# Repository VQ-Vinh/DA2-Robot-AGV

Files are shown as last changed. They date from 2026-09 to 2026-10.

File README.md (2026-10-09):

<div align="center">

# 🤖 DA2 · Robot AGV kho hàng kiểu Kiva

**Xe tự hành chui gầm, nâng kệ hàng, chở tới trạm lấy hàng rồi trả về ô và tự đi sạc.**

ROS 2 Jazzy · Nav2 · Gazebo Harmonic · Raspberry Pi 4 · STM32F4 · FreeRTOS

[Mô phỏng & ROS 2](RasPi/README.md) · [Nhật ký quá trình](REPORT.md) · [Firmware STM32](STM32/)

</div>

---

## ✨ Xe làm được gì

| 📦 Nhận đơn | 🛞 Chui gầm & nâng kệ | 🚚 Chở tới trạm | 🔋 Tự sạc | 🚨 Xử lý sự cố |
|:---:|:---:|:---:|:---:|:---:|
| Hàng đợi, ưu tiên, huỷ đơn trên web | Lidar tìm 4 chân kệ, căn giữa ≤ 1 cm | Nav2 + vùng cấm, footprint đổi theo tải | Pin thấp thì về trạm, sạc đủ mới nhận đơn | Dừng khẩn, đường bị chặn, rơi kệ |

---

## 🗺️ Kho hàng

```mermaid
flowchart LR
    subgraph W["Tây kho"]
        IN(["🔵 Khu nhập hàng"])
        CH(["🟢 Trạm sạc"])
        PK(["🟠 Trạm lấy hàng"])
    end
    subgraph N["Dãy bắc · xe vào hướng +y"]
        N1[N1] --- N2[N2] --- N3[N3] --- N4[N4] --- N5[N5]
    end
    AISLE{{"Lối giữa rộng 2.45 m"}}
    subgraph S["Dãy nam · xe vào hướng −y"]
        S1[S1] --- S2[S2] --- S3[S3] --- S4[S4] --- S5[S5]
    end
    W <--> AISLE
    AISLE <--> N
    AISLE <--> S
```

8 kệ 0.75 × 0.75 m nằm trong 10 ô, cách nhau 1.1 m. Bố trí lấy từ một file duy nhất, [`shelves.yaml`](RasPi/src/agv_mission/config/shelves.yaml), từ đó sinh ra world Gazebo, danh sách dock của Nav2 và mặt nạ vùng cấm.

---

## 🧩 Kiến trúc

```mermaid
flowchart TB
    subgraph USER["👤 Người vận hành"]
        WEB["🌐 Web dashboard<br/>điện thoại / laptop"]
    end

    subgraph PI["🍓 Raspberry Pi 4 · ROS 2 Jazzy"]
        DASH["web_dashboard<br/>REST + SSE"]
        OM["order_manager<br/>hàng đợi · SQLite · sự cố"]
        NAV["Nav2<br/>planner · RPP · docking · behaviors"]
        LOC["AMCL + EKF<br/>imu_bias"]
        PM["payload_manager<br/>lọc scan · footprint"]
        SD["shelf_detector<br/>tìm 4 chân kệ"]
    end

    subgraph MCU["⚙️ STM32F407 · FreeRTOS"]
        SPD["PID tốc độ + feedforward"]
        ENC["Encoder"]
        DRV["L298N × 2"]
    end

    LIDAR(["📡 YDLidar"])
    IMU(["🧭 BNO055"])
    BAT(["🔋 INA226"])
    MOT(["4 × GA25-370"])

    WEB <-->|HTTP| DASH
    DASH <--> OM
    OM -->|goal, dock| NAV
    NAV -->|cmd_vel| MCU
    LIDAR --> PM --> NAV
    LIDAR --> SD --> NAV
    LOC --> NAV
    MCU -->|odom, IMU, pin| LOC
    IMU --> MCU
    BAT --> MCU
    SPD --> DRV --> MOT
    MOT --> ENC --> SPD
```

---

## 🔁 Một đơn hàng

```mermaid
sequenceDiagram
    autonumber
    actor U as 👤 Người vận hành
    participant OM as order_manager
    participant N as Nav2 / docking
    participant L as Cơ cấu nâng

    U->>OM: add ke_03 tram_lay_hang
    OM->>N: tới staging trước ô (đoạn cuối thẳng)
    OM->>N: chui gầm theo chân kệ (lidar)
    OM->>OM: kiểm tra hướng ≤ 8°
    OM->>L: nâng
    OM->>N: lùi ra · chở tới trạm
    OM-->>U: đã tới, chờ lấy hàng
    U->>OM: confirm
    OM->>N: về ô · vào ô theo bản đồ
    OM->>OM: kiểm tra hướng ≤ 8°, vị trí ≤ 10 cm
    OM->>L: hạ
    OM->>N: lùi ra · về trạm sạc
```

---

## 🚨 Khi có sự cố

```mermaid
flowchart LR
    E{"Sự cố"} -->|Dừng khẩn<br/>Đường bị chặn > 60 s| R["⏸️ Xe dừng<br/>chờ người"]
    E -->|Rơi kệ<br/>Cơ cấu nâng lỗi| F["⛔ Đơn lỗi<br/>kệ chưa rõ vị trí"]
    E -->|Lỗi trước khi nâng kệ| Q["↩️ Trả đơn về hàng đợi"]
    R -->|"Đã xử lý"| C["▶️ Làm lại đúng bước đang dở"]
    F -->|"shelf ke_xx Ny"| C2["📍 Cập nhật vị trí kệ"]
```

```mermaid
flowchart LR
    B["🔋 Pin < 30 % + 10 % dự trữ cho đơn"] --> G["Về trạm sạc"] --> H["Sạc tới 80 %"] --> J["Nhận đơn tiếp"]
```

---

## 🧭 Định vị

```mermaid
flowchart LR
    ENC["Encoder bánh"] --> WO["/wheel/odom<br/>vx tin được · wz kém"]
    GYRO["Gyro"] --> RAW["/imu/raw"] --> IB["imu_bias<br/>học bias khi bánh đứng yên"] --> IMU["/imu"]
    WO --> EKF["EKF"]
    IMU --> EKF
    EKF --> ODOM["/odom"]
    ODOM --> AMCL["AMCL + bản đồ"]
    SCAN["Lidar"] --> AMCL
    AMCL --> MAP["vị trí trên bản đồ"]
```

---

## 📊 Kết quả trong mô phỏng

8 đơn liên tiếp, có mô phỏng vùng chết động cơ giống firmware (≥ 100 RPM):

| | Trước khi chỉnh | Sau khi chỉnh |
|---|:---:|:---:|
| Đơn xong | 8/8 | **8/8** |
| Thời gian TB / đơn | 105 s | **88 s** |
| Quay thừa khi trả kệ (lớn nhất) | 4198° | **75°** |
| Nav2 phải tự hồi phục | nhiều lần | **0** |
| Góc trôi khi đứng yên 5 phút | 2.4°–12° | **0.05°** |

| Bài thử | Kết quả |
|---|---|
| Chui gầm theo chân kệ (kệ đặt lệch) | 6/6, lệch ngang ≤ 0.9 cm · theo bản đồ chỉ 2/6 |
| Đơn hàng + ưu tiên + huỷ | 3/3 |
| Sạc giữa chừng | 3/3 đơn, tự về sạc rồi làm tiếp |
| Sự cố (dừng khẩn, rơi kệ, tường chắn) | dừng khẩn & rơi kệ: 4/4 lần · tường chắn: 2/4 lần |

Cách đo, các lần sai và cách sửa: [REPORT.md](REPORT.md).

---

## 🛣️ Tiến độ

```mermaid
timeline
    title Các mốc chính
    09/2026 : Firmware STM32 · PID tốc độ
            : Chọn ROS 2 Jazzy + Gazebo Harmonic
    10/2026 : Mô phỏng · EKF · SLAM · Nav2
            : Web dashboard
            : Kiva 1 · nâng kệ · Kiva 2 · tìm chân kệ
            : Kiva 3 · đơn hàng · Kiva 4 · pin & sạc · Kiva 5 · sự cố
    Tiếp theo : Cầu nối UART Pi ↔ STM32
              : PCB · khung xe · chốt định vị mặt nâng
              : Chạy trên xe thật
```

---

## 🚀 Chạy thử

```bash
# WSL Ubuntu 24.04 + ROS 2 Jazzy (xem RasPi/README.md để cài)
cd ~/agv_ws && colcon build --symlink-install && source install/setup.bash
ros2 launch agv_gazebo sim.launch.py nav:=true
```

Sau đó mở **http://localhost:8080**, chọn kệ và trạm rồi bấm **Tạo đơn**.

---

## 📁 Cấu trúc repo

```mermaid
flowchart LR
    R["📂 Src"] --> RP["📂 RasPi/src<br/>ROS 2"]
    R --> ST["📂 STM32<br/>firmware"]
    R --> RE["📄 REPORT.md<br/>nhật ký"]
    R --> CA["📂 CAD<br/>mô hình FreeCAD"]
    RP --> D["agv_description<br/>URDF"]
    RP --> G["agv_gazebo<br/>world · sim · bài thử"]
    RP --> L["agv_localization<br/>EKF · imu_bias"]
    RP --> NV["agv_navigation<br/>SLAM · Nav2 · docking"]
    RP --> M["agv_mission<br/>đơn hàng · dashboard"]
    ST --> APP["App<br/>logic"]
    ST --> MOD["Modules<br/>driver"]
    ST --> CORE["Core<br/>CubeMX sinh"]
```

<div align="center">

Đồ án 2 · HK261

</div>

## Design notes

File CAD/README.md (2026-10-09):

# CAD – mô hình cơ khí xe AGV

File: `agv.FCStd` (FreeCAD 1.1). Mở bằng **File → Open**.

## Quy ước

- Đơn vị mm. Gốc toạ độ = `base_footprint` của URDF (mặt đất, tâm xe); X tiến, Y trái, Z lên.
- Giá trị âm trong `Params` phải gõ dạng `=-82 mm` (có dấu `=`), nếu không FreeCAD lưu thành chữ.
- Mọi kích thước nằm trong bảng **`Params`** (đầu cây Model). Sửa giá trị ở cột B rồi nhấn `Ctrl+R`, mô hình tự cập nhật. Cột C ghi nguồn; dòng có chữ `UOC LUONG` là số chưa đo trên linh kiện thật.
- Hai tấm mica là PartDesign Body (sketch + pad + lỗ), dùng để xuất DXF cắt laser. Động cơ, lidar và Pi là model tải về; bánh và gá động cơ tự vẽ.

## Các cụm

| Cụm | Nội dung |
|---|---|
| `Chassis` | 2 tấm mica 300 × 300 × 5 mm, 4 trụ ốc 100 mm. Tầng 1 có 4 chỗ khoét cho bánh, 4 lỗ chữ nhật 16 × 8 mm luồn dây động cơ, lỗ trụ, 8 lỗ M3 bắt gá động cơ, 4 lỗ M3 cho lidar, 4 lỗ M2.5 cho Pi |
| `Drive` | `WheelFL` = bánh "65 mm" (STEP: lốp Ø68 × 27, mâm, khớp nối lục giác 12 mm) + GA25-370 có encoder (STEP) + gá chữ L (tự vẽ); FR/RL/RR là Link tới FL. Bánh nằm gọn trong khung, mặt ngoài thụt vào 1.5 mm |
| `Lidar` | YDLidar X4 (lưới STL) trên 4 trụ M3 × 25 đặt đúng 4 chân đế, ở phía trước xe: tâm đầu quay tại x = 108 mm (`lidar_x`), đuôi quay về sau |
| `RasPi` | Raspberry Pi 4B (STEP) trên 4 trụ 10 mm, ở giữa xe (mép trước chui dưới đuôi lidar 8 mm, hở 5 mm theo chiều cao), xoay ngang: GPIO quay về sau (phía PCB), USB-C/HDMI quay về trước, USB/Ethernet quay sang trái |
| `PCB` | Hình giữ chỗ cho mạch PCB 120 × 120 mm trên 4 trụ 30 mm, phía sau Pi; 4 lỗ M3 trên tầng 1 (vị trí lỗ giả định cách mép 4 mm, sửa khi có file PCB thật) |
| `Battery` | Pin 3S 18650 + mạch BMS (STEP, 54 × 65 × 21 mm), nằm trên tầng 1 ngay dưới PCB, mạch BMS quay lên |
| `Lift` | Cơ cấu nâng dựng thử, theo linh kiện bán sẵn: mặt nâng 260 × 260 × 10 mm có 4 lỗ Ø9 cho đầu vít; mỗi góc một đai ốc đồng T8 (vành 22 mm, cao 15 mm) treo dưới mặt nâng bằng 2 trụ đồng M3 × 20, đi qua lỗ Ø24 ở tầng 2; 4 vít me T8 tại (±103, ±86) mm quay trong ổ bi F688ZZ ở tầng 1; 4 puly GT2 20 răng + đai kín 860 mm; động cơ bước NEMA17 (STEP, thân 42.3 × 42.3 × 40 mm, puly lỗ 5 mm, đầu nối quay về trước) đặt úp ngược trên tầng 1 ở (0, −124), đỡ bằng 4 trụ đồng M3 × 20 và 2 con lăn ép đai. Đổi `lift_pos` (0–30 mm) trong `Params` hoặc chạy `lift_demo.FCMacro` để xem chuyển động. Đai không tự cập nhật theo `Params` |

Chưa có: model 3D thật của PCB, cách giữ pin (dây đai hoặc gá), chốt định vị kệ và công tắc hành trình của cơ cấu nâng.

## Model tải từ GrabCAD

Thư mục `CAD/parts/` không đưa lên git (model của người khác); hình học đã được nhúng sẵn trong `agv.FCStd`.

| Linh kiện | Nguồn | Dùng |
|---|---|---|
| GA25 + encoder | grabcad.com/library/ga25-gear-motor-with-encoder-1 | STEP |
| Gá GA25 | grabcad.com/library/ga25-motor-bracket-1 | chỉ có DWG, FreeCAD chưa đọc được nên gá được vẽ lại theo ảnh, kích thước ước lượng |
| Raspberry Pi 4B | grabcad.com/library/raspberry-pi-4-model-b-1 | STEP |
| YDLidar X4 | grabcad.com/library/ydlidar-x4-4 | STL (lưới, không phải khối đặc) |
| Pin 3S 18650 | grabcad.com/library/3s-18650-li-ion-battery-1 | STEP (chỉ lấy 3 cell + mạch BMS; bỏ dây và băng keo) |
| Bánh 65 mm | grabcad.com/library/65mm-wheel-1 | STEP (đường kính ngoài thực 68 mm; khớp nối trong model là loại lỗ 3 mm, động cơ GA25 trục 4 mm cần loại lỗ 4 mm) |
| NEMA17 42 × 42 | grabcad.com/library/nema-17-stepper-motor-42x42mm-dimension-accurate-cad-model-1 | STEP, có bản vẽ kích thước kèm theo |

## Khác với URDF

- Bánh Ø68 mm thay vì Ø65 mm: trục bánh cao 34 mm.
- `track_width` = 270 mm thay vì 340 mm: bánh nằm trong khung 300 mm.
- `plate1_below_axle` = 17.5 mm thay vì 12.5 mm (theo gá động cơ, ước lượng). Mặt trên tầng 2 ở 161.5 mm (URDF 155 mm); mặt nâng khi hạ ở 173.5 mm (URDF 167 mm, gầm kệ 180 mm).
- Trụ ốc nằm ở (±135, ±105) mm thay vì 4 góc, để tránh chỗ khoét bánh.
- Lidar dời lên trước 108 mm (URDF `lidar_x` = 0), thân cao 58.4 mm (URDF 35 mm), đặt trên trụ 25 mm; mặt quét tính ra ở 119.9 mm.

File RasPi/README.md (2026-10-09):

# RasPi – ROS 2 cho AGV kho hàng

ROS 2 **Jazzy** (Ubuntu 24.04) + **Gazebo Harmonic**. Chạy mô phỏng trên PC (WSL), sau này chạy node thật trên Raspberry Pi 4.

| Package | Nội dung |
|---|---|
| `agv_description` | URDF/xacro xe skid-steer 4 bánh, lidar, IMU; cấu hình RViz |
| `agv_gazebo` | World kho hàng kiểu Kiva (sinh từ `shelves.yaml`), bridge Gazebo ↔ ROS 2, launch mô phỏng, node riêng cho mô phỏng (động cơ, cơ cấu nâng, bài thử) |
| `agv_localization` | EKF gộp odom bánh xe + IMU → `/odom`; dùng chung cho mô phỏng và xe thật |
| `agv_navigation` | SLAM (slam_toolbox), bản đồ kho `maps/warehouse`, dẫn đường Nav2 + vùng cấm + chui gầm kệ (docking), `payload_manager` (lọc scan, footprint theo tải); dùng chung cho mô phỏng và xe thật |
| `agv_mission` | Bố trí kho (`shelves.yaml`: ô kệ, kệ), vị trí có tên (trạm sạc, trạm lấy hàng...), nhiệm vụ định sẵn, gõ lệnh từ terminal hoặc web dashboard; dùng chung cho mô phỏng và xe thật |

## Tạo workspace (một lần)

Code nằm trong repo; workspace trong WSL chỉ symlink tới đây, nên sửa file ở Windows là WSL thấy ngay.

```bash
mkdir -p ~/agv_ws/src
ln -sfn /mnt/d/MyBK/HK261/DA2/Src/RasPi/src/agv_description ~/agv_ws/src/agv_description
ln -sfn /mnt/d/MyBK/HK261/DA2/Src/RasPi/src/agv_gazebo      ~/agv_ws/src/agv_gazebo
ln -sfn /mnt/d/MyBK/HK261/DA2/Src/RasPi/src/agv_localization ~/agv_ws/src/agv_localization
ln -sfn /mnt/d/MyBK/HK261/DA2/Src/RasPi/src/agv_navigation   ~/agv_ws/src/agv_navigation
ln -sfn /mnt/d/MyBK/HK261/DA2/Src/RasPi/src/agv_mission      ~/agv_ws/src/agv_mission
cd ~/agv_ws && colcon build --symlink-install
source ~/agv_ws/install/setup.bash
```

Build lại chỉ khi thêm file mới. Sửa file có sẵn (`.xacro`, `.sdf`, `.yaml`, `.py`) thì không cần build lại vì đã dùng `--symlink-install`.

## Xem mô phỏng (từng bước)

1. **Mở terminal Ubuntu**: trong Windows Terminal chọn tab *Ubuntu-24.04*, hoặc gõ `wsl -d Ubuntu-24.04` trong PowerShell. `~/.bashrc` đã nạp sẵn ROS, workspace và biến GPU.
2. **Build** (chỉ cần khi có file mới, ví dụ sau khi `git pull`):
   ```bash
   cd ~/agv_ws && colcon build --symlink-install && source install/setup.bash
   ```
3. **Chạy mô phỏng kèm lập bản đồ**:
   ```bash
   ros2 launch agv_gazebo sim.launch.py slam:=true
   ```
   Sau ~15 giây sẽ hiện 3 cửa sổ:
   - **Gazebo**: kho 3D, xe ở đầu phía tây kho (x = −4.5). Bảng *Teleop* bên phải để lái, tia lidar được vẽ quanh xe.
   - **RViz** (nhìn từ trên xuống): bản đồ đang được vẽ (xám = chưa biết, trắng = trống, đen = vật cản), chấm đỏ = tia lidar, mũi tên vàng = vị trí EKF.
   - **rqt_robot_steering**: 2 thanh trượt tốc độ tiến / quay.
4. **Cho xe chạy**, chọn một trong hai cách:
   - Lái tay bằng bảng Teleop hoặc rqt_robot_steering. Lái **chậm, quay chậm**, đi qua hết các lối đi.
   - Cho xe tự đi hết lộ trình qua các lối đi (~2.5 phút). Mở terminal thứ hai:
     ```bash
     ros2 run agv_gazebo drive_route.py --ros-args -p rot_start:=0.6 -p rot_stop:=0.45
     ```
     Hai tham số `rot_*` dùng khi vùng chết động cơ đang bật (mặc định). Chạy với `rpm_min:=0` thì bỏ hai tham số này.
5. **Lưu bản đồ** khi đã đi hết kho (terminal thứ hai):
   ```bash
   ros2 run nav2_map_server map_saver_cli -f /mnt/d/MyBK/HK261/DA2/Src/RasPi/src/agv_navigation/maps/warehouse --ros-args -p save_map_timeout:=30.0
   ```
6. **Tắt**: Ctrl+C ở terminal đang chạy `ros2 launch`.

**Cho xe tự đi (Nav2)** trên bản đồ đã lưu:
```bash
ros2 launch agv_gazebo sim.launch.py nav:=true
```
- RViz mở `agv_navigation/rviz/nav.rviz` (từ cấu hình mặc định của Nav2, gọn hơn): bản đồ trắng/đen, các ô kệ mini là vùng cấm, chấm đỏ = lidar, đường xanh = đường Nav2 lập, ô mờ quanh xe = local costmap. Global costmap (lớp tím/xanh phủ cả kho) tắt sẵn, muốn xem thì tick lại trong *Displays → Global Planner*.
- Xe xuất phát **ngay ở trạm sạc** (đang sạc, mũi quay vào khối tiếp điểm, map (−0.45, 0), hướng π); AMCL đã đặt sẵn vị trí này. Khi chạy SLAM (`slam:=true`) xe tự xuất phát ở gốc bản đồ (world −4.5, 0). Nếu đặt xe chỗ khác (`x:= y:= yaw:=`, toạ độ world), bấm **2D Pose Estimate** rồi kéo chuột tại chỗ xe đứng.
- Bấm **Nav2 Goal**, click vào điểm đích trên bản đồ rồi kéo chuột để chọn hướng. Xe tự lập đường (đường xanh) và đi tới.

**Chạy nhiệm vụ kho** (bước 5). Tự chạy khi khởi động:
```bash
ros2 launch agv_gazebo sim.launch.py nav:=true mission:=tuan_tra
```
Hoặc chạy `nav:=true` rồi gõ lệnh ở terminal thứ hai:
```bash
ros2 run agv_mission agv_cmd.py list                      # vị trí và nhiệm vụ
ros2 run agv_mission agv_cmd.py goto tram_lay_hang        # đi tới một vị trí
ros2 run agv_mission agv_cmd.py run tuan_tra --follow     # chạy nhiệm vụ, in tiến độ tới khi xong
ros2 run agv_mission agv_cmd.py cancel                    # dừng
```
Lệnh mới: `seq khu_nhap_hang:pick tram_lay_hang:drop:2 tram_sac:charge` (chuỗi tự tạo, mỗi bước `vị_trí[:task[:giây chờ]]`), `goto_xy 1.5 1.0 0` (đi tới điểm bất kỳ, frame `map`).

**Web dashboard** (chạy sẵn cùng `mission.launch.py` / `sim.launch.py nav:=true`): mở `http://localhost:8080` trên PC, hoặc `http://<IP Tailscale của máy chạy>:8080` từ điện thoại (trên xe thật: `http://sms-pi:8080`). Trên trang có bản đồ + vị trí xe + đường Nav2, nút **DỪNG**, chạy nhiệm vụ định sẵn, tạo chuỗi nhiệm vụ, ô kệ (vùng cấm) tô đỏ, bấm một trạm trên bản đồ để đi tới, chế độ "Bấm để đi" tới điểm bất kỳ, và nhật ký. Tắt bằng `dashboard:=false`, đổi cổng bằng `port:=...`. **Chưa có đăng nhập**, chỉ mở trong LAN / Tailscale.

| API | |
|---|---|
| `GET /api/config` | vị trí và nhiệm vụ (từ `stations.yaml`, `missions.yaml`) |
| `GET /api/map` | bản đồ `/map` (ô base64, 255 = chưa biết) |
| `GET /api/keepout` | mặt nạ vùng cấm `/keepout_filter_mask` (các ô kệ mini), cùng dạng |
| `GET /api/events` | Server-Sent Events 5 Hz: `pose`, `path`, `state`, `log`, `link` |
| `POST /api/command` | `{"cmd": "run tuan_tra"}`: các lệnh `goto`, `goto_xy`, `run`, `seq`, `cancel`, `status`, `list` |

Ví dụ ra lệnh từ phần mềm khác (WMS): `curl -X POST localhost:8080/api/command -d '{"cmd":"run tuan_tra"}'`.

Trên RViz, các vị trí hiện thành đĩa màu có tên (xanh lá = trạm sạc, cam = trạm lấy hàng, xanh dương = khu nhập hàng, xám = điểm trên lối). Trong Gazebo, các trạm và ô kệ là vạch sơn trên sàn.

Sự cố thường gặp:

| Hiện tượng | Cách xử lý |
|---|---|
| Không cửa sổ nào hiện, hoặc tiêu đề cửa sổ có `[WARN:COPY MODE]` | WSLg bị treo: chạy `wsl --shutdown` trong PowerShell rồi mở lại Ubuntu |
| Cửa sổ Gazebo tắt (driver NVIDIA D3D12 của WSL segfault khi khởi tạo OpenGL cùng lúc với RViz, ~1/4 lần chạy) | Launch tự mở lại cửa sổ (tối đa 4 lần, log "Cua so Gazebo crash (driver GPU), mo lai"). Mô phỏng, RViz, SLAM vẫn chạy vì server và cửa sổ là 2 tiến trình riêng. Mở tay: `gz sim -g --gui-config ~/agv_ws/install/agv_gazebo/share/agv_gazebo/config/gui.config` |
| RViz báo lỗi `indexed_8bit_image ... GLSL link result` | Lỗi đã biết của rviz2 ([ros2/rviz#463](https://github.com/ros2/rviz/issues/463)), bản đồ vẫn hiện bình thường, bỏ qua |
| `ros2 topic echo/list` không ra gì | `ros2 daemon stop; ros2 daemon start`, hoặc thêm `--no-daemon` |

## Chạy

```bash
ros2 launch agv_gazebo sim.launch.py    # Gazebo (có bảng Teleop) + RViz + rqt_robot_steering
```

Lái xe (chọn một):

| Cách | Dùng cho | Ghi chú |
|---|---|---|
| Bảng **Teleop** bên phải Gazebo | Chỉ mô phỏng | Nút mũi tên, thanh trượt, hoặc bật *Keyboard* rồi dùng W/A/S/D |
| Cửa sổ **rqt_robot_steering** | Mô phỏng + xe thật | 2 thanh trượt. Lần đầu **bỏ tick ô "stamped"** (bridge nhận `Twist`), rqt sẽ nhớ |
| `ros2 run teleop_twist_keyboard teleop_twist_keyboard` | Mô phỏng + xe thật | Bàn phím trong terminal |

Tham số: `rviz:=false`, `steering:=false`, `headless:=true` (không mở cửa sổ nào), `x:= y:= yaw:=` (vị trí xuất phát, world; mặc định `auto` = trạm sạc, hoặc gốc bản đồ khi SLAM), `rpm_min:=0` (tắt vùng chết động cơ, xem mục dưới).

Chỉ xem model, không cần Gazebo: `ros2 launch agv_description display.launch.py`

## Mô hình động cơ (`motor_model`)

DiffDrive của Gazebo quay bánh đúng tốc độ được yêu cầu, kể cả rất chậm. Xe thật thì không: firmware STM32 ép mọi lệnh khác 0 vào khoảng **100–270 RPM** (`SPD_RPM_MIN/MAX` trong `STM32/App/Inc/speed_ctrl.h`), vì dưới ~30 % duty động cơ không quay nổi. Node `motor_model` đứng giữa `/cmd_vel` và Gazebo, làm y hệt những gì node cầu nối Pi ↔ STM32 (bước 1–2) và firmware (bước 3) sẽ làm:

```
teleop / Nav2 -> /cmd_vel -> motor_model -> /cmd_vel_limited -> DiffDrive (gz /model/agv/cmd_vel)
```

1. **Giữ bán kính cua** (`preserve_turning_radius`, giống `diff_drive_controller` của Clearpath Husky): bánh khác 0 mà dưới 100 RPM thì nhân **cả hai bánh** cùng tỉ lệ cho tới khi bánh chậm nhất đạt 100 RPM. Xe đi nhanh hơn nhưng đúng đường cong.
2. Bánh vượt 270 RPM: thu nhỏ cả hai bên cùng tỉ lệ (cũng giữ bán kính cua).
3. Firmware: bánh nào còn khác 0 mà dưới 100 RPM thì đẩy lên 100 RPM (= 0.34 m/s).

| Xin | Xe chạy | Ghi chú |
|---|---|---|
| tiến 0.10 m/s | tiến **0.34 m/s** | không đi chậm hơn được |
| quay tại chỗ 0.5 rad/s | quay **1.51 rad/s** | |
| v = 0.25, ω = 0.33 (bán kính 0.76 m) | v = 0.48, ω = 0.64 (bán kính 0.76 m) | nhanh hơn, **đúng đường cong** |
| tiến 1.5 m/s | tiến 0.92 m/s (tối đa) | |

> **Node cầu nối Pi ↔ STM32 trên xe thật phải làm bước 1.** Nếu chỉ có bước 3 (firmware), lệnh `v = 0.25, ω = 0.33` thành hai bánh cùng 100 RPM: xe đi thẳng, **mất lái**. Trong mô phỏng, Nav2 khi đó trôi vào kệ ở lối hẹp 1 m và hỏng 3/4 điểm đích. Tắt bước 1 để thử: `--ros-args -p preserve_turning_radius:=false`.

Bảng Teleop trong Gazebo cũng đi qua `motor_model` (bridge chuyển gz `/cmd_vel` sang ROS `/cmd_vel`).

## Định vị: EKF gộp odom bánh xe + IMU

```
Gazebo DiffDrive -> /sim/wheel_odom -> wheel_odom (thêm covariance) -> /wheel/odom --+
                                                                                     +--> EKF -> /odom + TF odom -> base_footprint
Gazebo IMU -> /imu/raw -> imu_bias (trừ bias gyro, học lúc bánh đứng yên) -> /imu ---+
```

- Odom bánh xe tính góc rất kém vì skid-steer trượt ngang khi quay. EKF lấy **vx** từ bánh xe và **tốc độ quay wz từ gyro** (cấu hình và giải thích trong `agv_localization/config/ekf.yaml`).
- Không dùng yaw tuyệt đối của BNO055: nó dựa vào từ kế, trong kho nhiều sắt thép nên không tin được.
- Gyro trong mô phỏng có bias nhỏ (~0.03 °/s) giống IMU thật. Không bù thì xe đứng yên 10 phút góc trôi 24°, và AMCL không kéo lại được (lidar lệch hẳn bản đồ, REPORT.md 4.15). Node `imu_bias` (agv_localization, `ekf.launch.py` tự chạy) coi mọi tốc độ quay đo được khi bánh đứng yên quá 1 s là bias, lấy trung bình trượt 5 s rồi trừ đi. Sau khi bù: đứng yên 5 phút trôi 0.05°.
- Trên xe thật, node cầu nối STM32 phải gửi `/wheel/odom` **có covariance** (giống `wheel_odom.py`) và BNO055 gửi **`/imu/raw`**; khi đó chạy `ros2 launch agv_localization ekf.launch.py` là xong.

## Đo sai số odom

`/ground_truth` là vị trí thật của xe trong world (chỉ có trong mô phỏng). So sánh với odom:

```bash
ros2 run agv_gazebo odom_drift.py                                          # /odom (EKF)
ros2 run agv_gazebo odom_drift.py --ros-args -p odom_topic:=/wheel/odom    # odom bánh xe
```

Lái xe một lúc rồi Ctrl+C, node in sai số vị trí, sai số góc và % quãng đường. Muốn đo hai nguồn cùng lúc thì đặt tên node khác nhau: thêm `-r __node:=drift_wheel`.

Kết quả (xuất phát `x:=-4.4 y:=-2.5 yaw:=1.5708`, ~7.5 m gồm đi thẳng, quay tại chỗ, chạy vòng; 2 lần chạy):

| | Lệch vị trí cuối | Lệch góc lớn nhất |
|---|---|---|
| Odom bánh xe `/wheel/odom` | 0.20–0.24 m (2.7–3.0 %) | 9.0–9.1° |
| EKF `/odom` | **0.09–0.12 m (1.2–1.5 %)** | **2.4–3.4°** |

## Lập bản đồ: slam_toolbox

```bash
ros2 launch agv_gazebo sim.launch.py slam:=true      # mô phỏng
ros2 launch agv_navigation slam.launch.py            # xe thật (cần /scan, /odom, TF)
```

Cấu hình `agv_navigation/config/slam.yaml` là **nguyên file mặc định** `mapper_params_online_async.yaml` của slam_toolbox, chỉ đổi `max_laser_range` thành 10 m (YDLidar X4). Cách làm này giống [linorobot2](https://github.com/linorobot/linorobot2) (dự án AGV DIY dùng Jazzy + Gazebo Harmonic + YDLidar). Kiến trúc DiffDrive → EKF (odom vx, vy, wz + gyro wz) → slam_toolbox cũng giống linorobot2 và robot mẫu `sam_bot` của [Nav2](https://github.com/ros-navigation/navigation2_tutorials).

> **Đừng chỉnh tham số SLAM khi chưa đo.** Lần đầu mình hạ `minimum_travel_distance/heading` từ 0.5 xuống 0.2 và `map_update_interval` từ 5 s xuống 2 s. Kết quả là SLAM quá tải ("Message Filter dropping message... queue is full"), TF map → odom trễ tới 1.7 s, bản đồ đầy vệt chéo, chỉ 25–36 % ô vật cản nằm đúng chỗ. Trả về mặc định thì hết.

Kết quả (lộ trình `drive_route.py`, ~52 m qua mọi lối đi, chấm bằng cách so ô vật cản với tường/kệ thật trong world):

| | Ô vật cản cách vật thật ≤ 10 cm | Sai lệch trung vị |
|---|---|---|
| Không vùng chết (`rpm_min:=0`), quay 0.5 rad/s | 98.4 % | 2.8 cm |
| Có vùng chết (mặc định, quay ≥ 1.5 rad/s) | **99.4 %** | **2.7 cm** |

Bảng trên là của kho cũ. Bản đồ trong repo (`maps/warehouse.pgm/.yaml`) là của **kho kiểu Kiva** (mục dưới), lập lại sau khi hạ lidar xuống 0.12 m: 100 % ô vật cản cách vật thật ≤ 10 cm (91.6 % ≤ 5 cm, trung vị 1.8 cm), thấy đủ 32/32 chân kệ mini. Gốc frame `map` là chỗ xe xuất phát (world x = −4.5, y = 0).

## Dẫn đường: Nav2

```bash
ros2 launch agv_gazebo sim.launch.py nav:=true       # mô phỏng
ros2 launch agv_navigation navigation.launch.py      # xe thật (cần /scan, /odom, TF)
```

Làm theo [linorobot2](https://github.com/linorobot/linorobot2):
- `agv_navigation/config/nav2.yaml` là **file mặc định của Nav2 Jazzy**, chỉ thay khối bộ điều khiển bằng khối của linorobot2. Khối đó dùng **RotationShim** (quay tại chỗ về hướng đường đi) kết hợp **Regulated Pure Pursuit** (bám đường, ~0.4 m/s). Kiểu chạy này hợp với xe có vùng chết.
- Chỉnh theo vùng chết động cơ (REPORT.md 4.14): RPP không xin chậm hơn 0.35 m/s (`min_approach_linear_velocity`, `regulated_linear_scaling_min_speed`) và quay tại chỗ 1.5 rad/s; `velocity_smoother` gần như bỏ giới hạn gia tốc (động cơ tự giới hạn); docking nới `undock_linear/angular_tolerance` 0.10 m / 0.3 rad; `behavior_server` 20 Hz. Thiếu các chỉnh này thì xe quay tròn tại staging khi docking thử lại, vọt lố 30–80° sau mỗi lần quay tại chỗ, đi vòng quanh đích.
- Đổi thêm: bán kính xe 0.25 m, lidar 10 m, AMCL đặt sẵn vị trí ban đầu ở gốc bản đồ, AMCL `alpha1–4: 0.05` và `z_hit/z_rand: 0.95/0.05` (xem mục dưới).
- `navigation.launch.py` gọi thẳng `bringup_launch.py` của Nav2 (map_server + AMCL + navigation).

**Vùng cấm cho pallet (kho cũ).** Lidar quét cao 17 cm không thấy pallet 15 cm. Lần chạy đầu, Nav2 lập đường sát pallet_2 và xe húc vào. Bánh quay trượt nên odom vẫn tăng, AMCL bị kéo lệch 3.8 m. Đã thêm **keepout filter** của Nav2, cấu hình lấy từ [nav2_costmap_filters_demo](https://github.com/ros-navigation/navigation2_tutorials):
- `maps/keepout_mask.pgm/.yaml`: mặt nạ cùng kích thước với bản đồ, pixel đen là vùng cấm.
- Tạo lại khi đổi bản đồ: `python3 scripts/make_keepout_mask.py`. Kho Kiva: lidar đã thấy pallet, vùng cấm giờ là **các ô kệ mini** (đọc từ `shelves.yaml`) và **chỉ ở global costmap** (xem mục Kiva).

Kết quả: 4 điểm đích qua các lối đi (lối dưới, phía đông giữa 2 pallet, lối hẹp giữa hàng A–B, về chỗ xuất phát), có vùng chết động cơ:

| Cấu hình | Thành công | Thời gian mỗi điểm | Lệch thật tại đích |
|---|---|---|---|
| Nav2 mặc định + linorobot2, chưa vùng cấm | 1/4 | — | xe húc pallet, AMCL lệch 3.8 m |
| + vùng cấm pallet | 3/4 | — | mất lái trong lối hẹp (xem mục mô hình động cơ) |
| + giữ bán kính cua, lần 1–3 | **4/4, 4/4, 4/4** | 13–44 s | 0.10–0.30 m |
| + giữ bán kính cua, lần 4 | 1/4 | — | AMCL lệch ở khu phía đông (xem dưới) |
| + chỉnh AMCL theo số đo (3 lần) | **4/4, 4/4, 4/4** | 13–30 s | 0.12–0.26 m |

Dung sai đích của Nav2 là 0.25 m, tính theo vị trí AMCL. Lệch thật có thể lớn hơn một chút vì AMCL tự nó lệch khoảng 0.1–0.2 m.

**AMCL lệch ở khu phía đông (đã sửa).** Với tham số AMCL mặc định của Nav2, khi xe chạy sang khu phía đông, AMCL lệch dần 0.3–1.1 m (2/3 lần đo bị lạc hẳn tới 6 m). Xe thật đi quá, dừng sát tường và kẹt. Các phép đo để tìm nguyên nhân:
- Đặt scan lên bản đồ theo vị trí thật: khớp 97–100 %, nên **bản đồ đúng**.
- Scan đều có TF, AMCL vẫn cập nhật đều, thời gian của lidar không lệch (τ ≈ 0–0.1 s).
- Đám hạt AMCL **tản rộng tới 1.8 m**. Tự chấm điểm từng hạt theo mô hình của AMCL: hạt điểm cao nhất cách vị trí thật 1–6 cm, nhưng chỉ hơn hạt trung bình khoảng 2.3 lần. Vị trí AMCL báo ra là trung bình cả đám nên bị kéo lệch.
- Nguyên nhân: `alpha1–4 = 0.2` giả định odom sai khoảng 45 %, trong khi odom EKF đo được chỉ sai 2–3 %. Mỗi lần xe quay tại chỗ (rất nhiều, do vùng chết), đám hạt phình ra. Thêm vào đó `z_hit/z_rand = 0.5/0.5` làm điểm của các hạt ít khác nhau.
- Cách sửa: `alpha1–4: 0.05`, `z_hit: 0.95, z_rand: 0.05` (mặc định của AMCL ROS 1). Kết quả: sai số định vị lớn nhất còn 0.14–0.16 m, 12/12 điểm đích, không còn "collision ahead".

## Kho kiểu Kiva: chui gầm, nâng kệ, chở tới trạm

Xe chui vào gầm **kệ mini 4 chân**, nâng kệ lên ~1.7 cm, chở cả kệ tới trạm lấy hàng (mô hình "hàng tới người" của Amazon Kiva), rồi trả kệ về ô.

**Bố trí** (`agv_mission/config/shelves.yaml`, nguồn duy nhất): 10 ô (2 dãy × 5, cách nhau 1.1 m) hai bên lối giữa rộng 2.45 m, 8 kệ, ô N5 và S5 để trống. Kệ 0.75 × 0.75 m, gầm cao 0.18 m, nặng 3 kg (kệ 1 kg + hàng 2 kg). Sửa file này rồi chạy:
```bash
python3 agv_gazebo/scripts/make_warehouse.py
python3 agv_navigation/scripts/make_keepout_mask.py
```
(`make_warehouse.py` ghi world và danh sách dock trong `nav2.yaml`; đổi vị trí ô thì lập lại bản đồ trước khi tạo vùng cấm.)

**Xe:** lidar đặt **giữa 2 tầng** (mặt quét 0.12 m): trên nóc thì bị đáy kệ che khi chui gầm; ở đây lidar thấy cả pallet 15 cm. Tầng 2 có **mặt nâng** (khớp `lift_joint`, hành trình 3 cm, 2 cm/s như vít me) và cảm biến "có kệ".

| Node | Việc | Xe thật |
|---|---|---|
| `lift_sim.py` (agv_gazebo) | `/lift/command` (`up`/`down`) → khớp nâng; phát `/lift/state` (`down`/`moving_up`/`up`/`moving_down`/`error`), `/lift/has_load` | cầu nối STM32 phát đúng các topic này |
| `shelf_detector.py` (agv_navigation) | `/scan_raw` → `/detected_dock_pose`: tâm kệ gần xe nhất (frame lidar, stamp của scan) | dùng nguyên |
| `payload_manager.py` (agv_navigation) | `/scan_raw` → `/scan`: bỏ điểm 4 trụ ốc của xe, khi chở thì bỏ cả 4 chân kệ; đổi footprint costmap (xe 0.32 × 0.38 m ↔ kệ 0.84 × 0.84 m); giới hạn 0.35 m/s khi chở; xoá costmap khi mặt nâng lên hết | dùng nguyên |

**Chui gầm** dùng `docking_server` của Nav2 (`SimpleNonChargingDock`), mỗi ô là một dock `slot_N1`…`slot_S5`. Xe tới **staging** cách tâm ô 1.0 m, rồi tiến thẳng vào. Hai loại dock:
- `shelf_dock` (**lấy kệ**): chui theo **kệ thật**. Node `shelf_detector.py` (agv_navigation, dùng chung xe thật) tìm 4 chân kệ trong `/scan_raw` (4 cụm điểm nhỏ tạo hình vuông cạnh 0.72 m), phát tâm kệ lên `/detected_dock_pose`. Kệ trả về mỗi lần lệch vài cm, lâu dần sẽ lệch nhiều; AMCL cũng lệch ~5 cm, nên không tin vị trí ô trên bản đồ.
- `slot_dock` (**trả kệ** vào ô trống, không có chân nào để nhận diện): theo vị trí ô trên bản đồ. Gửi `DockRobot` với `use_dock_id: false`, `dock_pose` = tâm ô, `dock_type: slot_dock`.
- Tới staging qua một điểm cách thêm 1.2 m trên cùng trục ô (`NavigateThroughPoses`), để đoạn cuối là đường thẳng: quay tại chỗ với vùng chết thì vọt lố 30–50°.
- **Kiểm tra tư thế trước khi nâng / hạ** (`checked_dock` trong `order_manager`): docking chỉ kiểm khoảng cách tới tâm ô, không kiểm hướng, nên có lúc báo xong khi xe lệch 22–50°. Lệch hướng > `dock_yaw_tol_deg` (8) hoặc, khi trả kệ, lệch vị trí > `dock_pos_tol` (0.10 m) thì lùi thẳng ra staging vào lại (`dock_attempts` 3). Lệch > `turn_min_deg` (40) thì quay tại chỗ bớt trước (Spin quay thừa ~`spin_coast_deg` 30°, nên lệch nhỏ không chỉnh tại chỗ được).
- **Mô phỏng khoá kệ vào mặt nâng** khi nâng hết (plugin `DetachableJoint` trong mỗi kệ, `lift_sim` gửi `/shelf/<kệ>/attach|detach` qua `gz topic`), hạ thì mở khoá trước. Xe thật cần **chốt định vị** trên mặt nâng tương ứng. `lift_sim ... -p lock_shelves:=false` để chở chỉ bằng ma sát như trước.
- Vùng cấm (ô kệ) **chỉ ở global costmap**: để ở local costmap thì bộ điều khiển docking coi mép vùng cấm là vật cản.
- `docking_server` của Jazzy phát thẳng `cmd_vel` (không qua collision monitor), nên **giữ** kiểm tra va chạm của nó.

Thử cả chu trình (lấy kệ → trạm lấy hàng → trả về ô → trạm sạc), đo bằng vị trí thật:
```bash
ros2 launch agv_gazebo sim.launch.py nav:=true
ros2 run agv_gazebo shelf_transport_test.py --ros-args -p shelf:=ke_03 -p station:=tram_lay_hang
# kệ đặt lệch khỏi tâm ô (dx m, dy m, dyaw độ); detect:=false để so với cách chui theo bản đồ
ros2 run agv_gazebo shelf_transport_test.py --ros-args -p shelf:=ke_03 -p shelf_offset:="[0.08, -0.06, 4.0]" -p detect:=false
# 8 đơn liên tiếp, đo quỹ đạo thật từng bước (góc quay thừa, tư thế khi trả kệ); CSV ở ~/agv_tests/motion_<tag>.csv
ros2 run agv_gazebo motion_test.py m1
```
Kết quả `motion_test.py` có vùng chết (REPORT.md 4.14): trước khi sửa 8/8 đơn xong, TB 105 s, nhưng có bước chui gầm / trả kệ quay thừa ~4200°; sau khi sửa 8/8, TB 88 s, quay thừa khi trả kệ TB 28° (max 75°), không lần nào Nav2 phải hồi phục.

So sánh khi kệ bị dời lệch như sau nhiều lần trả kệ: (+8, −6 cm, 4°), (−7, +5 cm, −5°), (+10, 0 cm, 0°), mỗi kiểu thử `ke_03` và `ke_06` (vùng chết 100 RPM):

| | Chui theo chân kệ (`shelf_dock`) | Chui theo ô trên bản đồ (`slot_dock`) |
|---|---|---|
| Chui gầm lấy kệ thành công | **6/6** | 2/6 |
| Chu trình trọn vẹn (10 bước) | **6/6** | 2/6 |
| Lệch ngang so với kệ thật | **0.0–0.9 cm** | 1.6–10.9 cm |
| Lệch góc so với kệ thật | 0.4–1.9° | 1.6–34.6° |
| Lệch dọc so với tâm kệ (xe dừng quá) | 3.8–6.1 cm | 3.1–3.9 cm (2 lần chui được) |

Theo bản đồ thì xe vào đúng ô nhưng lệch kệ thật, docking dự báo quẹt chân kệ và bỏ cuộc. Còn lại: xe luôn dừng quá tâm kệ ~4–6 cm (đi ≥ 0.34 m/s vì vùng chết), nên kệ nằm lệch tâm mặt nâng chừng đó.

Kết quả (6 lần mỗi cấu hình, 3 kệ ở 2 dãy: `ke_01`, `ke_03`, `ke_06`, mỗi lần 10 bước):

| | Vùng chết 100 RPM (firmware hiện tại) | 50 RPM (nếu cải thiện tốc độ thấp) |
|---|---|---|
| Chu trình trọn vẹn | **6/6** | **6/6** |
| Lệch góc tại staging (TB / lớn nhất) | 17.8° / 42.6° | 5.2° / 13.0° |
| Lệch góc tại staging khi chở kệ | 33.3° / 66.3° | 8.5° / 13.6° |
| Sau khi chui gầm lấy kệ (ngang / góc, lớn nhất) | 5.5 cm / 3.3° | 4.1 cm / 0.7° |
| Kệ trả về lệch tâm ô | 3.1–8.7 cm | 0.6–5.6 cm |
| Thời gian một chu trình | 74–107 s | 98–119 s |

Bộ điều khiển docking nắn được cả góc lệch 66° ở staging nhờ khe 15 cm giữa xe và chân kệ. Hạ vùng chết xuống 50 RPM thì xe tới staging thẳng hơn 4 lần và đặt kệ chính xác hơn, đổi lại chạy chậm hơn ~20 s.

## Đơn hàng: `order_manager`

Một đơn = "đưa kệ X tới trạm lấy hàng Y". Node `order_manager.py` (agv_mission, chạy sẵn cùng `mission.launch.py` / `sim.launch.py nav:=true`, dùng chung xe thật) giữ **hàng đợi** và làm lần lượt:

```
tới trước ô (thẳng trục ô) -> chui gầm (shelf_dock, theo chân kệ) -> nâng -> lùi ra -> chở tới trạm
-> CHỜ NGƯỜI XÁC NHẬN đã lấy hàng -> tới trước ô -> trả kệ (slot_dock) -> hạ -> lùi ra -> đơn tiếp / về trạm sạc
```

- **Lệnh** (`/order/command`, hoặc trên dashboard): `add <kệ> <trạm> [ưu tiên]` (ưu tiên lớn làm trước), `cancel <id>` (đơn đang chờ; đơn đang chạy chỉ huỷ được trước khi nâng kệ), `confirm` (người ở trạm đã lấy hàng), `pause` / `resume` (dừng / tiếp nhận đơn mới), `ack` (đã xử lý lỗi).
- **Trạng thái:** `/order/state` (JSON, giữ tin cuối): hàng đợi theo đúng thứ tự sẽ làm, đơn đang chạy + bước, vị trí từng kệ, lịch sử, thống kê. Nhật ký: `/order/status`.
- **Dữ liệu:** SQLite `~/.agv/orders.db` (bảng `orders`, `shelves`). Mô phỏng nạp lại vị trí kệ từ `shelves.yaml` mỗi lần chạy (`reset_shelves:=true`, vì world cũng đặt lại kệ). Đơn đang chạy lúc mất điện được đánh dấu lỗi khi khởi động lại.
- **Lỗi:** mỗi chặng thử lại 1 lần (xoá costmap). Lỗi trước khi nâng kệ → đơn "lỗi", làm đơn sau. Lỗi khi **đang chở kệ** → xe dừng, dashboard báo đỏ, chờ người xử lý rồi bấm "Đã xử lý" (`ack`).
- `auto_confirm_s:=N` tự xác nhận sau N giây (thử nghiệm); mặc định 0 = chờ người bấm.
- **Dashboard** có thẻ *Đơn hàng*: tạo đơn (kệ, trạm, thường/gấp), hàng đợi (huỷ), nút **"Đã lấy hàng xong — trả kệ"** khi xe chờ ở trạm, lịch sử, thời gian trung bình; bản đồ vẽ từng kệ ở ô của nó, kệ đang chở vẽ theo xe.
- Không dùng song song với nhiệm vụ của `mission_server` (cả hai cùng gửi đích cho Nav2).

**Pin và tự về sạc.** `/battery_state` (`sensor_msgs/BatteryState`) do `battery_sim.py` (mô phỏng: pin 3S 9.9–12.6 V, hao theo thời gian + tốc độ + khi chở kệ, sạc khi xe chạm tiếp điểm trạm sạc) hoặc cầu nối STM32 đọc INA226 (xe thật) phát. Trạm sạc `tram_sac` có khối tiếp điểm cao 0.15 m (lidar thấy), xe tiến vào bằng `docking_server` (`SimpleChargingDock`, dock `charger_tram_sac`, xác nhận "đang sạc" bằng dòng > 0.5 A).
- Rảnh thì vào trạm sạc. Trước mỗi đơn: pin < `battery_low` (30 %) + `order_reserve` (10 %, phần pin cho chính đơn đó) thì không nhận đơn, sạc tới `battery_full` (80 %) rồi làm tiếp. Đơn đang chạy luôn được làm xong.
- Vào trạm: đi thẳng vào staging dọc trục trạm (như với kệ), rồi `DockRobot`. Rời trạm: `UndockRobot`; lỗi thì lùi thẳng 0.5 m (behavior `BackUp`).
- Dashboard: ô **Pin** trên thanh trên (đỏ khi đang giữ để sạc, ⚡ khi đang sạc).
- Thử nhanh: `ros2 launch agv_gazebo sim.launch.py nav:=true battery_time_scale:=8 battery_initial:=0.45` (hao / sạc nhanh gấp 8).

Kết quả (pin đầu 45 %, nhanh gấp 8, 3 đơn): 3/3 đơn xong; sau đơn 1 pin 30 % → dừng nhận đơn, vào trạm, sạc 28 → 80 %, rời trạm làm 2 đơn còn lại, hết đơn thì về sạc (57–77 s mỗi đơn).

Thử trong mô phỏng (3 đơn, 1 đơn gấp, 1 đơn huỷ, tự bấm xác nhận sau 3 s), 2 lần: mỗi lần **3/3 đơn xong, đơn huỷ không chạy, 0 lỗi**; đơn gấp chạy trước đơn thường tạo trước nó; 59–111 s mỗi đơn (TB 85 s); kệ về ô lệch 1.7–8.1 cm. Lần 2 có 2 chặng (1 lần chui gầm, 1 lần lùi ra) báo va chạm, thử lại thì qua.

## Xử lý sự cố

`order_manager` giám sát 5 Hz trong lúc chạy đơn:

| Sự cố | Phát hiện | Xe làm gì | Người làm gì |
|---|---|---|---|
| Dừng khẩn | nút **DỪNG KHẨN** (`order estop`) | huỷ mọi action, vận tốc 0 | bấm **Đã xử lý** → xe làm tiếp đúng bước đang dở |
| Đường bị chặn | Nav2 tự hồi phục (feedback `number_of_recoveries`) hoặc không tiến về đích > 15 s (`distance_remaining`) → cảnh báo vàng; > 60 s hoặc chặng lỗi hẳn → sự cố | dừng | dọn đường, **Đã xử lý** → đi tiếp |
| Rơi kệ khi đang chở | mất tín hiệu "có kệ" > 1 s | dừng, đơn lỗi, kệ "chưa rõ vị trí" | đặt lại kệ, `order shelf <kệ> <ô>`, **Đã xử lý** |
| Cơ cấu nâng lỗi | `/lift/state` = `error` | dừng | sửa, **Đã xử lý** |
| Lỗi một bước khi đang chở kệ | bất kỳ | dừng (không bỏ đơn, không chạy lại từ đầu vì xe đang đội kệ) | **Đã xử lý** → làm lại bước đó |
| Lỗi trước khi nâng kệ | bất kỳ | trả đơn về hàng đợi (tối đa 2 lần), làm đơn khác | — |

Thử bằng gây sự cố có chủ ý trong mô phỏng (`agv_gazebo/scripts/fault_test.py`, chạy cùng `sim.launch.py nav:=true`): 3 tình huống (tường chắn ngang kho 75 s khi đang chở kệ; DỪNG KHẨN khi đang chở; dịch kệ ra khỏi xe khi đang chở): lần f7 **3/3 đạt** — cảnh báo rồi sự cố `duong_bi_chan`, gỡ tường + Đã xử lý → đơn xong; lần f10 2/3 (tường: có cảnh báo, đơn xong sau khi gỡ, nhưng chưa thành sự cố trong 75 s vì xe men theo tường về phía đích nên vẫn được tính là tiến); dừng khẩn xe đứng yên (0.0 cm trong 3 s) rồi làm tiếp, đơn xong; rơi kệ phát hiện sau 1.7 s, đơn lỗi, kệ chưa rõ vị trí → `shelf ke_02 N5` cập nhật đúng.

## Nhiệm vụ kho: `agv_mission`

```
agv_cmd.py ──/mission/command──► mission_server ──NavigateToPose──► Nav2
                                     │
                                     ├─/mission/status   (tiến độ, giữ tin cuối)
                                     └─/mission/stations (MarkerArray cho RViz)
```

- `config/stations.yaml`: vị trí có tên trong frame `map`: `tram_sac` (chỗ xe xuất phát), `tram_lay_hang` (tây nam), `khu_nhap_hang` (tây bắc), `loi_tay`, `loi_dong` (hai đầu lối giữa). Ô kệ nằm ở `shelves.yaml`.
- `config/missions.yaml`: lộ trình đơn giản (`tuan_tra`). Chở kệ theo đơn hàng sẽ do `order_manager` lo (giai đoạn sau); hiện thử bằng `shelf_transport_test.py`.
- `mission_server.py` chờ `bt_navigator` "active" rồi mới gửi đích. Chặng thất bại thì xoá costmap, đợi 3 s và thử lại 1 lần; vẫn thất bại thì bỏ qua và đi tiếp. Hết nhiệm vụ thì in dòng `TONG KET` kèm thời gian từng chặng. Tham số launch: `mission:=<tên>`, `repeat:=<số lần>`.
- Trên xe thật: chạy `navigation.launch.py` + `ros2 launch agv_mission mission.launch.py`. Toạ độ trong `stations.yaml` phải đo lại trên bản đồ của kho thật.

## Topic

| Topic | Kiểu | Chiều |
|---|---|---|
| `/cmd_vel` | `geometry_msgs/Twist` | ROS → `motor_model` (và Teleop Gazebo → ROS) |
| `/cmd_vel_limited` | `geometry_msgs/Twist` | `motor_model` → Gazebo DiffDrive |
| `/ground_truth` | `nav_msgs/Odometry` | Gazebo → ROS, frame `world`, chỉ để đánh giá |
| `/sim/wheel_odom` | `nav_msgs/Odometry` | Gazebo → `wheel_odom`, covariance = 0 |
| `/wheel/odom` | `nav_msgs/Odometry` | `wheel_odom` → EKF (xe thật: node cầu nối STM32) |
| `/odom`, `/tf` (odom → base_footprint) | `nav_msgs/Odometry`, `tf2_msgs/TFMessage` | EKF → SLAM, Nav2 |
| `/map`, `/tf` (map → odom) | `nav_msgs/OccupancyGrid` | slam_toolbox → RViz, Nav2 |
| `/scan_raw` (7 Hz, 720 tia, 0.12–10 m) | `sensor_msgs/LaserScan` | Gazebo → `payload_manager` (xe thật: driver YDLidar) |
| `/scan` | `sensor_msgs/LaserScan` | `payload_manager` → SLAM, AMCL, Nav2 |
| `/lift/command`, `/lift/state`, `/lift/has_load` | `std_msgs/String`, `String`, `Bool` | cơ cấu nâng (`lift_sim` / cầu nối STM32) |
| `/lift/cmd_pos`, `/lift/contact` | `std_msgs/Float64`, `ros_gz_interfaces/Contacts` | `lift_sim` ↔ Gazebo |
| `/imu/raw` (100 Hz) | `sensor_msgs/Imu` | Gazebo → ROS (xe thật: BNO055) → `imu_bias` |
| `/imu` | `sensor_msgs/Imu` | `imu_bias` (đã trừ bias gyro) → EKF |
| `/joint_states`, `/clock` | | Gazebo → ROS |

## Kích thước xe

Đặt ở đầu `agv_description/urdf/agv.urdf.xacro`: thân 2 tầng mica 30 × 30 cm cách nhau 10 cm, 4 trụ ốc ở góc, linh kiện ở tầng 1, lidar đặt trên khối linh kiện **giữa 2 tầng** (mặt quét cao ~0.12 m), mặt nâng trên tầng 2, bánh 65 mm. Giá trị đánh dấu `(*)` là ước lượng (track 0.34 m, wheelbase 0.20 m, độ dày mica...), cần đo xe thật rồi sửa.

Lidar quét ở ~0.12 m: thấy pallet 15 cm và chân kệ mini, không thấy vật thấp hơn 12 cm. 4 trụ ốc giữa 2 tầng che lidar vài độ; `payload_manager` lọc bỏ.

`effective_track` (0.45 m) là track hiệu dụng cho skid-steer: bánh trượt ngang khi quay nên xe quay ít hơn tính theo `track_width`. Hiệu chỉnh bằng cách cho xe quay tại chỗ rồi đặt `effective_track` mới = `effective_track` hiện tại × `góc_odom / góc_thật`.

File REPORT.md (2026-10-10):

# Nhật ký quá trình làm đồ án DA2 – Robot AGV kho hàng

Tài liệu này ghi lại **quá trình** làm đồ án để làm báo cáo cho giảng viên: làm gì, dùng công cụ gì, **sai ở đâu, vì sao sai, sửa thế nào và rút ra gì**. Nó không phải hướng dẫn sử dụng (xem `RasPi/README.md`). Đồ án thật không đi thẳng từ đầu tới đích, nên các lần thử hỏng được ghi lại đầy đủ như các lần thành công.

Quy ước mỗi mục:
- **Mục tiêu**: định làm gì.
- **Cách làm**: công cụ, thiết kế.
- **Sai lầm / sự cố**: chuyện gì xảy ra, số liệu.
- **Nguyên nhân**: tìm ra bằng cách nào.
- **Cách sửa** và **kết quả** sau khi sửa.
- **Bài học**.

---

## 1. Tổng quan

**Đề tài:** AGV (xe tự hành) chạy trong kho hàng: lập bản đồ, tự định vị, tự đi tới các vị trí kệ.

**Phần cứng dự kiến:**

| Khối | Linh kiện |
|---|---|
| Máy tính trên xe | Raspberry Pi 4 (4 GB), Ubuntu Server 24.04, ROS 2 Jazzy |
| Vi điều khiển | STM32F4 Discovery (STM32F407), FreeRTOS, nối với Pi qua UART (USART2) |
| Động cơ | 4 × GA25-370 có encoder, kiểu skid-steer (4 bánh thường), 2 × driver L298N |
| Cảm biến | YDLidar X2/X4 (USB), IMU BNO055, đo pin INA226, PiCamera |
| Khung | 2 tầng mica 30 × 30 cm cách nhau 10 cm, bánh 65 mm |

**Kiến trúc phần mềm:**
```
Pi (ROS 2):  Nav2 ── SLAM / AMCL ── EKF (odom bánh + IMU) ── node cầu nối UART ──┐
STM32:                                       điều khiển tốc độ 4 bánh (PID) ◄────┘
```

**Phương pháp:** làm firmware điều khiển động cơ trước, sau đó **làm toàn bộ phần ROS trong mô phỏng Gazebo trước khi lắp xe**. Mục tiêu là các file cấu hình ROS (EKF, SLAM, Nav2) dùng lại nguyên khi chạy trên Pi.

**Công cụ:**

| Mục đích | Công cụ |
|---|---|
| Firmware | STM32CubeMX (sinh code HAL, FreeRTOS), CMake + arm-none-eabi-gcc, ST-Link |
| Công cụ PC | Python (vẽ log tốc độ, chỉnh PID trực tiếp qua UART) |
| ROS 2 / mô phỏng | ROS 2 Jazzy, Gazebo Harmonic, RViz2, robot_localization, slam_toolbox, Nav2 |
| Môi trường PC | Windows 11 + WSL2 Ubuntu 24.04 (GPU RTX 3050 qua driver D3D12) |
| Quản lý mã | Git + GitHub, mỗi phần việc một nhánh và một pull request (PR) |
| Hỗ trợ | Trợ lý AI (Claude Code) viết code, chạy test, phân tích log; người làm đồ án quyết định hướng đi và kiểm tra kết quả |

**Mốc thời gian:**

| Ngày | Việc | PR |
|---|---|---|
| 19/09/2026 | Dựng project STM32, nháy LED | #1 |
| 25/09/2026 | Điều khiển tốc độ 1 động cơ (PID + feedforward), FreeRTOS, UART CLI | #2 |
| 25–26/09/2026 | Chọn môi trường ROS 2, dựng mô hình xe và kho trong Gazebo, cài Pi | #3 |
| 07/10/2026 | Bước 1 mô phỏng: giới hạn động cơ thật | #4 |
| 07/10/2026 | Bước 2: EKF gộp odom bánh xe + IMU | #5 |
| 07/10/2026 | Bước 3: SLAM lập bản đồ kho | #6 |
| 07/10/2026 | Bước 4: Nav2 tự dẫn đường + vùng cấm | #7 |
| 07/10/2026 | Nhật ký quá trình (tài liệu này) + skill ghi báo cáo | #8 |
| 07/10/2026 | Bước 5: nhiệm vụ kho (trạm sạc, khu nhận hàng, kịch bản + lệnh), video demo | #9 |
| 07–08/10/2026 | Sửa vấn đề còn mở: AMCL lệch ở khu phía đông, "collision ahead" trong lối hẹp | #10 |
| 08/10/2026 | Web dashboard giao nhiệm vụ qua trình duyệt | #11 |
| 08/10/2026 | Giảm tải mô phỏng: bước vật lý 1 ms → 3 ms | #12 |
| 08/10/2026 | Kho kiểu Kiva, giai đoạn 1: chui gầm, nâng, chở kệ | #13 |
| 08/10/2026 | Kho Kiva, giai đoạn 2: nhận diện kệ bằng chân kệ | #14 |
| 08/10/2026 | Kho Kiva, giai đoạn 3: quản lý đơn hàng | #15 |
| 08/10/2026 | Kho Kiva, giai đoạn 4: pin và tự về sạc | #16 |
| 08/10/2026 | Kho Kiva, giai đoạn 5: xử lý sự cố | #17 |
| 09/10/2026 | Xe vòng vòng / trả kệ lệch: vùng chết động cơ, kiểm tra tư thế, khoá kệ | #17 |
| 09/10/2026 | Lidar lệch bản đồ (bias con quay), cửa sổ Gazebo crash (driver WSL) | #17 |
| 09/10/2026 | Gộp #14–#17 vào `main`; README gốc thành trang giới thiệu có sơ đồ (kiến trúc, tiến độ, cấu trúc repo) | #18 |
| 09/10/2026 | Mô hình cơ khí FreeCAD: khung, động cơ + bánh, lidar, Raspberry Pi, PCB (giữ chỗ), pin, cơ cấu nâng | #20 |
| 09–10/10/2026 | Mạch PCB: chốt linh kiện, sơ đồ chân STM32 cho 4 bánh + nâng, sơ đồ nguyên lý KiCad theo khối, rà soát linh kiện thừa, bản xếp PCB nháp | #21 |

---

## 2. Firmware STM32: điều khiển tốc độ động cơ

### 2.1. Dựng project
- **Cách làm:** cấu hình ngoại vi trong STM32CubeMX (file `.ioc`), build bằng CMake. Code tự viết đặt riêng trong `STM32/Modules` (driver) và `STM32/App` (logic), không sửa vào `Core/` do CubeMX sinh ra.
- **Lý do:** CubeMX sinh lại các file trong `Core/` mỗi lần đổi cấu hình, code tự viết để lẫn trong đó có nguy cơ bị ghi đè. Quy tắc "CubeMX trước, code sau, code riêng ở Modules/App" được ghi thành skill của project (`.claude/skills/stm32-cubemx-first`) để luôn làm đúng.

### 2.2. Driver động cơ, encoder, PID
- **Cách làm:**
  - TIM1 phát PWM 1 kHz cho L298N, TIM3 ở chế độ đọc encoder.
  - Đo đặc tuyến thật duty → RPM của động cơ: 30 % → 96.5 RPM, … , 100 % → 278.6 RPM.
  - Bộ điều khiển = **feedforward nội suy từ bảng đo** + PID rời rạc có anti-windup, chu kỳ 50 ms.
- **Sự cố:** dưới khoảng 30 % duty động cơ không quay (ma sát tĩnh, gọi là **vùng chết**). Firmware vì thế giới hạn tốc độ đặt khác 0 trong khoảng **100–270 RPM**. Hệ quả của quyết định này hiện ra rất rõ ở phần mô phỏng (mục 4.1 và 4.4).
- **Chỉnh PID:** đo tự động bằng bài thử 0 → 120 → 240 → 120 RPM (không tải):

  | Kp / Ki / Kd | Vọt lố 0→120 | Ổn định TB | Sai số xác lập |
  |---|---|---|---|
  | 0.12 / 0.50 / 0.01 | 11.3 % | 2.60 s | 1.6 RPM |
  | 0.20 / 0.50 / 0.01 | 9.1 % | 2.35 s | 1.3 RPM |
  | **0.20 / 0.90 / 0.01** (chọn) | 14.7 % | **1.63 s** | **0.1 RPM** |
  | 0.20 / 0.90 / 0.03 | 18.0 % | 1.57 s | 0.2 RPM |

  Kd gần như vô tác dụng vì feedforward đã gánh phần lớn; tăng Kd chỉ làm vọt lố tệ hơn.

### 2.3. FreeRTOS và UART
- **Sự cố:** ban đầu task log in ra UART kiểu polling (`printf` → `HAL_UART_Transmit`). CPU đứng chờ từng byte, khoảng 3.3 ms mỗi dòng, chiếm **~7 % CPU**.
- **Cách sửa:** chuyển sang **UART + DMA**. Task giao buffer cho DMA rồi chờ semaphore, CPU rảnh trong lúc truyền. Tải CPU của task log còn khoảng 0.1 %.
- **Kết quả:** task điều khiển chạy đúng chu kỳ 50 ms (`osDelayUntil`), log không làm lệch nhịp điều khiển. Sơ đồ thời gian ở `STM32/docs/rtos-task-timing.md`.

**Còn lại cho phần cứng:** mới điều khiển 1 động cơ / 1 encoder; cần mở rộng lên 4 bánh, giao thức UART với Pi, driver BNO055 / INA226.

---

## 3. Chọn môi trường ROS 2 và dựng mô phỏng (PR #3)

### 3.1. Sai lầm chọn môi trường: ROS 2 Humble trên Ubuntu 22.04
- **Sự cố:** máy đã có WSL Ubuntu 22.04 + ROS 2 Humble. Gazebo bị crash ngay khi mở (lỗi Ogre2 `GL3PlusTextureGpu::copyTo`).
- **Nguyên nhân:** Mesa trên Ubuntu 22.04 chỉ cho OpenGL 4.2 qua D3D12, trong khi Gazebo mới cần ≥ 4.3. Kho PPA Mesa mới không còn hỗ trợ bản 22.04.
- **Cách sửa:** tạo WSL **Ubuntu 24.04** mới + **ROS 2 Jazzy + Gazebo Harmonic**, giữ nguyên bản 22.04 cũ. Pi cũng cài Ubuntu 24.04 + Jazzy để hai bên cùng phiên bản.
- **Sự cố tiếp theo:** mặc định WSL dùng card AMD tích hợp (OpenGL 4.2) hoặc render bằng CPU. Phải đặt `GALLIUM_DRIVER=d3d12` và `MESA_D3D12_DEFAULT_ADAPTER_NAME=NVIDIA` thì mới dùng RTX 3050 với OpenGL 4.6.

### 3.2. Mạng giữa PC và Pi
- **Sự cố:** các node ROS 2 trên PC và Pi không thấy nhau. Router chặn multicast giữa các thiết bị Wi-Fi. Trong WSL, gói discovery lớn hơn 1500 byte bị mất trên loopback.
- **Cách sửa:** cấu hình Fast DDS bằng file XML: chỉ định card mạng, khai báo sẵn địa chỉ peer qua Tailscale, giới hạn kích thước message.

### 3.3. Mô hình xe và kho
- **Cách làm:** URDF xe theo kích thước thật (các số chưa đo được đánh dấu là ước lượng), lidar và IMU giả lập, kho 12 × 8 m có 8 kệ và 2 pallet.
- **Sai lầm:** odom của xe skid-steer báo góc quay sai (odom 163° trong khi xe thật quay 124°). Bánh trượt ngang khi quay nên xe quay ít hơn công thức của xe 2 bánh.
- **Cách sửa:** dùng "track hiệu dụng" `effective_track = 0.45 m` (track thật khoảng 0.34 m), hiệu chỉnh bằng cách cho quay tại chỗ rồi so góc. Husky của Clearpath (xe skid-steer thương mại) cũng làm cách này, với `wheel_separation_multiplier = 1.875`.

---

## 4. Mô phỏng từng bước

### 4.1. Bước 1 – Làm mô phỏng "khó" như xe thật (PR #4)
- **Mục tiêu:** mô phỏng không được dễ hơn thực tế, nếu không cấu hình chỉnh trong mô phỏng sẽ hỏng khi lên xe.
- **Cách làm:**
  - Node `motor_model` đứng giữa `/cmd_vel` và Gazebo, áp đúng giới hạn 100–270 RPM của firmware.
  - Thêm vị trí thật `/ground_truth` và công cụ `odom_drift.py` để đo sai số.
- **Phát hiện:** vùng chết có hệ quả lớn:

  | Lệnh xin | Xe thật chạy |
  |---|---|
  | tiến 0.10 m/s | 0.34 m/s (không đi chậm được) |
  | quay tại chỗ 0.5 rad/s | 1.51 rad/s |
  | cua bán kính 0.5 m | cua bán kính 1.9 m |

- **Sự cố khi test:** xe lao vào tường hoặc kệ trong bài test vì vòng cua bị nới rộng. **Sửa:** cho các bài test xuất phát ở vùng trống phía tây kho.
- **Kết quả:** odom bánh xe lệch 0.30 m (5.4 %) và góc lệch tới 21° sau khoảng 5.5 m.

### 4.2. Bước 2 – EKF gộp odom bánh xe và IMU (PR #5)
- **Cách làm:** `robot_localization` lấy vận tốc tiến từ bánh xe và tốc độ quay từ gyro. Không dùng góc tuyệt đối của BNO055, vì nó dựa vào từ kế, mà trong kho nhiều sắt thép.
- **Sự cố:** odom của Gazebo gửi covariance (độ tin cậy) bằng 0, tức "chắc chắn tuyệt đối", khiến EKF bỏ qua IMU. **Sửa:** node `wheel_odom` gán covariance hợp lý, đúng việc node cầu nối STM32 sau này phải làm.
- **Thêm cho sát thực tế:** gyro có bias nhỏ (~0.03 °/s). Không có bias thì góc không bao giờ trôi, và EKF trong mô phỏng sẽ đẹp hơn thực tế.
- **Kết quả:** lệch góc lớn nhất giảm từ **9° xuống 2.4–3.4°**, lệch vị trí từ 0.24 m xuống 0.12 m.

### 4.3. Bước 3 – SLAM lập bản đồ (PR #6): sai lầm lớn nhất của đồ án
- **Mục tiêu:** dùng `slam_toolbox` lập bản đồ kho.
- **Lần 1 – tự chỉnh tham số:** đổi `minimum_travel_distance/heading` từ 0.5 xuống 0.2 và cập nhật bản đồ mỗi 2 s thay vì 5 s, "cho bản đồ dày hơn". Kết quả bản đồ đầy **vệt chéo**, tường bị thủng. Chỉ **25–36 %** ô vật cản nằm đúng chỗ (lệch ≤ 10 cm). Điểm chấm do script tự viết: so từng ô trên bản đồ với tường và kệ thật trong world.
- **Bốn lần đoán sai liên tiếp:**
  1. Xe quay nhanh do vùng chết → viết `scan_gate` bỏ scan khi quay. **Không cải thiện.**
  2. Xe bị chúi hoặc nảy làm lidar nghiêng → đo roll/pitch: **bằng 0**, sai.
  3. Lidar trả về 10 m thay vì "vô cực" khi không chạm gì → kiểm tra: trả về `inf` đúng chuẩn, sai.
  4. Điểm "ma" ở mép kệ (mixed pixel) → viết bộ lọc shadow. **Tệ hơn**: lọc mất 7.9 % điểm, gồm cả tường thật, SLAM mất dấu.
- **Bước ngoặt:** người làm đồ án yêu cầu dừng đoán, đi xem các dự án mã nguồn mở làm thế nào. Đối chiếu với **linorobot2** (AGV tự chế, cùng Jazzy + Gazebo Harmonic + YDLidar), robot mẫu **sam_bot** trong hướng dẫn Nav2, và **Clearpath Husky**:
  - Kiến trúc DiffDrive → EKF → slam_toolbox giống hệt của đồ án.
  - Họ dùng **nguyên file tham số mặc định** của slam_toolbox, không có bộ lọc scan tự viết.
- **Cách sửa:** trả cấu hình về mặc định, chỉ đổi tầm lidar 10 m, bỏ mọi bộ lọc tự chế.
- **Kết quả:** **99.4 %** ô vật cản đúng chỗ, lệch trung vị 2.7 cm, ngay lần chạy đầu tiên.
- **Nguyên nhân thật:** cấu hình tự chỉnh làm SLAM xử lý dày gấp đôi, bị quá tải. Log có "Message Filter dropping message… queue is full" và TF trễ tới 1.7 s. Vùng chết, thứ bị nghi đầu tiên, **không phải** nguyên nhân: chạy với vùng chết bản đồ vẫn sạch.
- **Sự cố phụ:**
  - Lưu bản đồ bị hết thời gian chờ (mặc định 2 s, DDS trong WSL kết nối chậm) → đặt `save_map_timeout:=30`.
  - Cửa sổ Gazebo thỉnh thoảng crash trong driver GPU của WSL, kéo theo cả hệ thống tắt → tách server và cửa sổ Gazebo thành 2 tiến trình như linorobot2. Cửa sổ chết thì mô phỏng vẫn chạy.
  - RViz báo lỗi shader khi vẽ bản đồ → tra ra là lỗi đã biết của rviz2 (issue ros2/rviz#463), vô hại.
- **Bài học:**
  - Gặp kết quả xấu thì **đối chiếu với dự án tham khảo và cấu hình mặc định trước**, đừng đoán rồi vá.
  - Đổi từng thứ một và đo bằng số.
  - "Chỉnh cho tốt hơn" mà không đo có thể làm hỏng hệ thống.

### 4.4. Bước 4 – Nav2 tự dẫn đường (PR #7)
- **Cách làm (theo linorobot2):** lấy file tham số mặc định của Nav2 Jazzy, chỉ thay bộ điều khiển bằng **RotationShim + Regulated Pure Pursuit**: quay tại chỗ về hướng đường rồi đi đều khoảng 0.4 m/s. Kiểu chạy này hợp với xe có vùng chết.
- **Đánh giá:** script gửi 4 điểm đích qua các lối đi, đo kết quả và độ lệch so với vị trí thật.

Các sự cố gặp phải, theo thứ tự:

| # | Sự cố | Nguyên nhân (tìm bằng cách nào) | Cách sửa |
|---|---|---|---|
| 1 | Launch lỗi ngay: `name 'false' is not defined` | Launch con kế thừa tham số `slam=false` của launch cha; Nav2 tính `not false` trong Python | Truyền rõ `slam: 'False'` cho Nav2 |
| 2 | Chỉ 1/4 điểm thành công, AMCL lệch 3.8 m | Nhật ký vị trí thật cho thấy xe **đứng yên** trong khi odom vẫn tăng: xe húc pallet cao 15 cm mà lidar (quét ở 17 cm) không thấy | **Vùng cấm (keepout)** cho pallet, theo demo chính thức của Nav2 |
| 3 | 3/4: xe trôi chéo vào kệ trong lối hẹp 1 m | Nhật ký lệnh: Nav2 xin `v=0.25, w=0.33`, ra bánh thành `v=0.34, w=0` → **mất lái**: cả 2 bánh dưới 100 RPM nên bị firmware đẩy lên bằng nhau | **Giữ bán kính cua**: nhân cả 2 bánh cùng tỉ lệ (giống `preserve_turning_radius` của Husky). Node cầu nối trên xe thật phải làm y vậy |
| 4 | Sau khi sửa, các lần chạy về sau lại hỏng; đã nghi WSL quá tải, rác bộ nhớ chia sẻ của DDS, rồi khởi động lại cả WSL | **Lỗi ở script test**: hàm chờ Nav2 của thư viện gửi lại vị trí ban đầu mỗi lần có message tới, các subscription ghi log làm nó gửi hàng chục lần/giây, AMCL reset liên tục | Script test tự chờ AMCL, không gửi vị trí ban đầu nữa |
| 5 | Nạp node vùng cấm vào chung container Nav2 → "xe không chạy", nên đã **bỏ cách này** | Thực ra lỗi do script ở dòng 4. Kết luận sai vì đo bằng công cụ đo đang hỏng | Sau khi sửa script, dùng lại cách container: đạt 4/4 |
| 6 | Chạy có cửa sổ thì vùng cấm không hiện | Bộ khởi động vùng cấm (tiến trình riêng) kẹt khi máy tải nặng | Nạp vào chung container Nav2, đúng mặc định của demo Nav2 |
| 7 | RViz mở trống trơn | Lúc đầu đoán do dòng chú thích trong file cấu hình (**đoán sai**). Thật ra file RViz mới chưa được cài vì chưa build lại workspace | Build lại; tự chụp cửa sổ RViz để kiểm tra trước khi báo |
| 8 | Hình xe trong RViz báo đỏ | Cấu hình gốc của Nav2 đăng ký `/robot_description` kiểu volatile nên bỏ lỡ message phát một lần lúc khởi động | Dùng cấu hình "transient local" như file RViz đã chạy tốt |

**Kết quả:** sau các sửa đổi, **4/4 điểm đích ở 4 lần chạy riêng** (13–45 s mỗi điểm, lệch thật 0.10–0.30 m). Có **1 lần 1/4** (mục 6).

**Bài học:**
- Khi một phép đo cho kết quả lạ, **kiểm tra công cụ đo trước** (sự cố 4–5). Một script test lỗi đã dẫn tới hai kết luận sai và mất nhiều lần chạy thử.
- Nhật ký "vị trí thật – vị trí ước lượng – lệnh xin – lệnh thực" theo thời gian tìm ra nguyên nhân nhanh hơn nhiều so với đoán (sự cố 2–3).
- Báo "đã sửa" chỉ khi đã tự kiểm tra kết quả (sự cố 7).

### 4.5. Bước 5 – Nhiệm vụ kho (PR #9)
- **Mục tiêu:** biến khả năng "đi tới một điểm" thành nhiệm vụ AGV. Kho có trạm sạc và khu nhận hàng. Ra lệnh được theo 2 cách: chạy kịch bản tự động, và gõ lệnh từ máy tính.
- **Cách làm:** package `agv_mission`, dùng chung cho mô phỏng và xe thật:
  - `stations.yaml`: 10 vị trí có tên (trạm sạc ở chỗ xe xuất phát, khu nhận hàng ở vùng trống tây nam, 8 điểm lấy hàng ở giữa lối đi phía nam mỗi kệ).
  - `missions.yaml`: 3 nhiệm vụ: `giao_hang` (3 chặng), `giao_hang_2` (4 chặng), `tuan_tra` (9 chặng).
  - `mission_server.py`: gửi từng đích cho Nav2 qua action `NavigateToPose`. Chặng thất bại thì xoá costmap, đợi 3 s và thử lại 1 lần. In dòng tổng kết kèm thời gian từng chặng.
  - `agv_cmd.py`: lệnh `list / goto / run / cancel / status`.
  - Trạm sạc và khu nhận hàng vẽ thành ô sơn trên sàn Gazebo (chỉ để nhìn, không va chạm, lidar không thấy) và thành đĩa màu có tên trên RViz.
  - Node điều phối **không dùng** `BasicNavigator`, vì lỗi gửi dồn vị trí ban đầu ở bước 4.

| # | Sự cố | Nguyên nhân (tìm bằng cách nào) | Cách sửa |
|---|---|---|---|
| 1 | Lần chạy đầu: 0/3 chặng, cả 3 bị "Nav2 từ chối đích" trong 0.6 s | Node coi Nav2 sẵn sàng khi action server có mặt và có vị trí AMCL, nhưng lúc đó `bt_navigator` chưa "active" nên từ chối mọi đích. Thử lại ngay cũng bị từ chối (log thời điểm từng dòng) | Hỏi trạng thái vòng đời `bt_navigator/get_state`, chờ "active", giống thư viện của Nav2; khi bị từ chối thì đợi 3 s rồi mới thử lại |
| 2 | Lệnh `goto ke_A1 --follow` thoát sau 6 s, khi xe chưa tới | Kênh `/mission/status` giữ lại 10 tin cũ cho node vào sau, trong đó có dòng "TONG KET" của nhiệm vụ trước. Công cụ chỉ bỏ qua tin cũ trong 0.5 s đầu, nhưng kết nối DDS trong WSL lâu hơn thế | Bỏ qua mọi tin nhận được trước khi gửi lệnh |
| 3 | Thời gian tính lại cho lần thử lại không được đặt lại, nên lần thử lại sẽ bị huỷ ngay (phát hiện khi đọc lại code, chưa xảy ra lúc chạy) | Dùng chung một mốc thời gian cho cả chặng và từng lần thử | Tách 2 mốc: bắt đầu chặng (tính tổng) và bắt đầu lần thử (tính timeout) |
| 4 | Công cụ quay video rò bộ nhớ, rồi đọc vùng nhớ đã giải phóng (phát hiện khi đọc lại code trước khi chạy) | Ảnh lấy bằng `XGetImage` không được giải phóng; sau khi thêm `XFree` lại đọc kích thước ảnh sau khi giải phóng | Lưu kích thước trước, rồi `XFree` |
| 5 | Trên RViz không thấy đĩa/tên vị trí, dù node phát đủ 20 marker (kiểm bằng subscriber riêng) | Lớp hiển thị nằm cuối danh sách. Giả thuyết: lớp vùng cấm (phủ cả bản đồ, mờ 50 %) vẽ đè lên; **chưa kiểm chứng riêng** | Đưa lớp Stations lên ngay dưới lớp Map thì hiện; đổi chữ tên sang màu tối cho dễ đọc trên nền trắng |

**Kết quả** (mô phỏng không cửa sổ, có vùng chết động cơ):

| Nhiệm vụ | Cách ra lệnh | Kết quả |
|---|---|---|
| `giao_hang` (3 chặng) | tự động, 4 lần (1 lần riêng + 3 lần lặp liên tiếp) | **4/4 lần đủ 3/3 chặng**: 62.0, 61.8, 60.6, 74.4 s |
| `tuan_tra` (9 chặng) | tự động | **9/9 chặng**, 152.4 s, không cần thử lại |
| `giao_hang_2` (4 chặng) | gõ lệnh `run` | **4/4 chặng**, 81.5 s, có 2 lần thử lại tự động (1 do bị lệnh trước chen ngang, 1 do lỗi TF thoáng qua lúc nhận đích mới) |
| `giao_hang` có cửa sổ (2 lần quay video) | tự động | 3/3 chặng, 62.8 và 61.4 s |

- Lần lặp thứ 3 của `giao_hang` chậm hơn (74.4 s so với khoảng 61 s): chặng tới khu nhận hàng mất 35.7 s thay vì khoảng 24 s. Log có 24 lần "collision ahead" và 3 lần "Controller patience exceeded"; bước tự gỡ bên trong Nav2 xử lý được nên xe vẫn tới đích.
- Video demo [`RasPi/docs/demo_giao_hang.mp4`](RasPi/docs/demo_giao_hang.mp4): nhiệm vụ `giao_hang`, ghép cửa sổ Gazebo + RViz + dòng trạng thái, 45 s (tua nhanh ×2). Chỉ chụp cửa sổ của WSL, không chụp màn hình Windows.

**Bài học:**
- "Có action server" chưa có nghĩa là "nhận lệnh được"; phải kiểm tra đúng trạng thái mà thư viện chuẩn kiểm tra.
- Kênh có giữ tin cũ (transient local) cần phân biệt tin cũ với tin mới.
- Đọc lại code trước khi chạy bắt được 2 lỗi (sự cố 3–4) mà test có thể không lộ ra.

### 4.6. Sửa 2 vấn đề còn mở: AMCL lệch và "collision ahead" (PR #10)
- **Mục tiêu:** sửa 2 vấn đề để lại từ bước 4 và 5:
  - AMCL lệch tới 1.1 m ở khu phía đông kho, có lần làm xe kẹt sát tường.
  - Bộ điều khiển báo "collision ahead" trong lối hẹp, làm chặng chậm hơn khoảng 50 %.
- **Cách làm:** theo bài học ở bước 3, đo để biết chuyện gì xảy ra, và đối chiếu tài liệu chính thức (Nav2), dự án tham khảo (Clearpath, linorobot2), mã nguồn gốc (AMCL ROS 1) trước khi sửa. Mỗi giả thuyết được kiểm bằng một phép đo riêng:

| # | Giả thuyết / câu hỏi | Phép đo | Kết quả |
|---|---|---|---|
| 1 | Hai vấn đề có liên quan nhau? | 3 lần chạy 4 điểm đích, ghi sai số TF `map → base_footprint` so với vị trí thật mỗi 0.5 s | Sai số lớn **chỉ** ở khu phía đông. 2/3 lần AMCL lạc tới 6 m. "Collision ahead" chỉ xuất hiện **sau** khi lạc, tức là hệ quả |
| 2 | Collision monitor gây kẹt? | Đọc issue của Nav2 ([navigation2#3313](https://github.com/ros-navigation/navigation2/issues/3313)) | Chế độ "approach" (đang dùng) vẫn cho lùi; xe kẹt vì đã vào sát tường do AMCL lệch. **Không phải nguyên nhân gốc** |
| 3 | Bản đồ khu phía đông sai? | Chụp scan ở khu phía đông, đặt lên bản đồ theo vị trí thật và theo vị trí AMCL | Theo vị trí thật khớp 97–100 %, theo AMCL 60 % → 5 %. **Bản đồ đúng** |
| 4 | AMCL bỏ scan vì TF odom trễ? | Với mỗi scan, kiểm tra TF `odom → laser_frame` tại đúng thời điểm của scan; đếm số lần AMCL cập nhật | 100 % scan có TF (scan chỉ mới hơn TF khoảng 3 ms); AMCL cập nhật 157 lần / 27.5 m. **Loại** |
| 5 | AMCL không sửa gì, chỉ chạy theo odom? | Theo dõi TF `map → odom` (phần hiệu chỉnh của AMCL) | Có hiệu chỉnh nhưng quá ít và sai hướng (cần khoảng (−0.23, −0.37) m, AMCL cho (−0.15, −0.04) m) |
| 6 | Lidar gắn lệch hoặc lật? | Đọc URDF / TF | `rpy = 0 0 0`, đúng. **Loại** |
| 7 | AMCL quá tự tin sai? | Chụp đám hạt (`/particle_cloud`) và covariance | Ngược lại: đám hạt **tản rộng tới 1.8 m** theo x (covariance x tới 3.1 m²) |
| 8 | Thời gian (stamp) của scan lệch? | Đặt scan theo vị trí thật tại `stamp + τ`, τ ∈ [−1, 1] s, tìm τ khớp nhất | τ tốt nhất 0 (55 %) hoặc −0.1 s (36 %), tương đương 2–3 cm. **Loại** |
| 9 | Mô hình đo của AMCL có phân biệt được hạt đúng? | Tự tính lại đúng công thức likelihood field của AMCL cho từng hạt | Hạt điểm cao nhất cách vị trí thật 1–6 cm (có đủ hạt đúng), nhưng chỉ hơn hạt trung vị khoảng **2.3 lần**. AMCL báo ra trung bình cả đám tản rộng, nên bị kéo lệch |

- **Nguyên nhân** (từ phép đo 7 và 9):
  - `alpha1–4 = 0.2` (mặc định Nav2) nghĩa là giả định odom sai khoảng 45 %, trong khi odom EKF đo được chỉ sai **2–3 %** quãng đường, và góc lấy từ gyro. Riêng `alpha4` làm đám hạt phình ra mỗi lần quay tại chỗ, mà xe quay tại chỗ rất nhiều vì vùng chết động cơ.
  - `z_hit/z_rand = 0.5/0.5` (mặc định Nav2) coi một nửa số đo là nhiễu, nên điểm của các hạt ít khác nhau.
  - Linorobot2 và Clearpath dùng nguyên mặc định này mà vẫn chạy được. Khác biệt ở xe này là quay tại chỗ nhiều (vùng chết) và kho có nhiều lối dài giống nhau.
- **Cách sửa** (`agv_navigation/config/nav2.yaml`, có ghi chú lý do):
  - `alpha1–4: 0.05` (tương đương sai số 22 %, vẫn dư nhiều so với 2–3 % đo được).
  - `z_hit: 0.95, z_rand: 0.05`: mặc định của AMCL ROS 1 (`AMCL.cfg`). Tính trên dữ liệu đã chụp, độ chênh hạt đúng / hạt trung vị tăng từ 2.3 lên 2.9 lần.
- **Kết quả** (cùng bài test 4 điểm đích, 3 lần mỗi cấu hình):

  | | Mặc định Nav2 | Sau khi sửa |
  |---|---|---|
  | Điểm đích thành công | 4/4, 2/4, 2/4 | **4/4, 4/4, 4/4** |
  | Sai số định vị: 90 % thời gian dưới | 0.24; 4.72; 4.65 m | **0.07; 0.07; 0.07 m** |
  | Sai số định vị lớn nhất | 0.54; 5.97; 6.08 m | **0.16; 0.15; 0.14 m** |
  | "Collision ahead" | 0; 0; 26 | **0; 0; 0** |

  Bài nhiệm vụ: `tuan_tra` 9/9 chặng (145.0 s, trước là 152.4 s, còn 4 lần "collision ahead"). `giao_hang` 3 lần đều 3/3 chặng (60.8, 69.2, 63.2 s), 0 lần "collision ahead"; trước khi sửa có một chặng mất 35.7 s với 24 lần "collision ahead". Lần 69.2 s có 1 lần tự thử lại do hệ thống khựng khoảng 1 s (vòng điều khiển tụt 9.6 Hz, TF cũ), không liên quan tới định vị.
- **Sai lầm trong quá trình:** ban đầu nghi collision monitor (giả thuyết 2), rồi nghi AMCL bỏ scan (4), rồi nghi lệch thời gian (8). Cả ba bị loại bằng đo đạc chứ không phải bằng thử sửa. Cũng đã định đổi `robot_radius` sang khung chữ nhật như Clearpath để giảm "collision ahead", nhưng số liệu cho thấy "collision ahead" là hệ quả của AMCL lệch, nên không đổi, để mỗi lần chỉ đổi một thứ.
- **Bài học:**
  - Hai triệu chứng có thể cùng một gốc; đo xem chúng xảy ra theo thứ tự nào trước khi sửa từng cái.
  - Mặc định của thư viện là điểm xuất phát tốt, nhưng khi số đo cho thấy giả định của nó (ở đây: độ nhiễu odom) sai lệch xa thực tế thì chỉnh theo số đo, và ghi lý do ngay trong file cấu hình.

### 4.7. Web dashboard giao nhiệm vụ (PR #11)
- **Mục tiêu:** người vận hành mở trình duyệt (điện thoại, laptop) qua LAN hoặc Tailscale để xem bản đồ, vị trí xe và giao nhiệm vụ, không phải cài ROS 2 hay gõ lệnh terminal.
- **Chọn web hay app Qt:** chọn web. Các AMR thương mại (MiR) và Open-RMF cho người vận hành dùng giao diện web; Qt chủ yếu dùng cho công cụ kỹ thuật (RViz, rqt). Lý do quyết định: trình duyệt chỉ cần HTTP tới Pi. Một app Qt phải tham gia DDS, mà mạng PC ↔ Pi ở mục 3.2 đã rất khó cấu hình.
- **Chọn mã nguồn mở hay tự viết:**

  | Dự án | Lý do không dùng làm giao diện chính |
  |---|---|
  | rosbridge_suite + roslibjs | Bản ROS 2 nặng: tác giả Vizanti ghi nhận nó không chạy nổi trên Pi 4 khi tải thường. Trình duyệt cũng phải biết cấu trúc topic ROS |
  | Vizanti (có bản Jazzy) | Nhắm robot ngoài trời (GPS, tàu, robot hiện trường), không có khái niệm kệ, trạm sạc, nhiệm vụ kho |
  | foxglove_bridge + Lichtblick | Công cụ debug kiểu RViz trên trình duyệt, hợp cho kỹ sư, không hợp cho người vận hành |
  | Open-RMF rmf-web | Dành cho cả đội robot, quá nặng cho 1 xe |

  Kết luận: tự viết một server nhỏ bằng thư viện chuẩn Python (không cài thêm gì lên Pi) và HTML/JS thuần. API theo nghiệp vụ (`run giao_hang`), giống REST API của MiR, và dùng lại nguyên `mission_server` của bước 5.
- **Cách làm:**
  - Node `web_dashboard.py` có các API: `GET /api/config`, `GET /api/map`, `GET /api/events` (Server-Sent Events 5 Hz: vị trí xe từ TF, đường đi `/plan`, trạng thái, nhật ký) và `POST /api/command`. Lệnh POST chỉ nhận các động từ cho phép và bị giới hạn độ dài.
  - `mission_server` có thêm topic `/mission/state` (JSON) cho chương trình đọc, và 2 lệnh mới: `seq` (chuỗi bước tự tạo) và `goto_xy` (đi tới điểm bấm trên bản đồ).
  - Giao diện gồm: bản đồ (canvas), nút DỪNG, nhiệm vụ định sẵn, trình tạo chuỗi nhiệm vụ, nút đi nhanh, nhật ký. Có bố cục cho điện thoại và giao diện sáng/tối.
- **Sai lầm / sự cố:**

  | # | Sự cố | Nguyên nhân (tìm bằng cách nào) | Cách sửa |
  |---|---|---|---|
  | 1 | Trợ lý AI bắt tay vào sửa code khi người làm đồ án mới hỏi "có nên làm không", bị dừng lại | Hiểu nhầm câu hỏi ý kiến thành yêu cầu làm | Hoàn tác, xoá nhánh; lập kế hoạch và so sánh phương án trước, được duyệt mới làm |
  | 2 | Bản đồ chỉ là một chấm nhỏ ở góc màn hình | `fit()` chạy khi canvas chưa có kích thước (W = 0, đọc biến `view` trong trình duyệt thấy tỉ lệ = −0.198) | Chưa có kích thước thì chưa fit, để `ResizeObserver` gọi lại |
  | 3 | Đọc mã thấy file web sẽ bị trả 404 khi build `--symlink-install` | `realpath` đi theo symlink ra ngoài thư mục web, nên phép kiểm tra chống `..` chặn luôn file hợp lệ | Dùng `abspath`: vẫn chặn `..`, giữ symlink; kiểm lại bằng `curl` đường dẫn `../../etc/passwd` → 404 |
  | 4 | Node dashboard tốn **82 % CPU** | So sánh: `mission_server` cũng tốn 77 %; một node rclpy **rỗng** bật `use_sim_time` tốn 53 %. Nguyên nhân là `/clock` của Gazebo (bước vật lý 1 ms, khoảng 1000 tin/giây), rclpy phải xử lý từng tin | Dashboard chỉ cần TF mới nhất nên bỏ `use_sim_time` → **8 %** (2 trình duyệt mở). Trên Pi không có `/clock` |
  | 5 | Khởi động lại node dashboard thì nhật ký trên trang bị lặp; bản sửa đầu tiên lại làm nhật ký trống | Id dòng nhật ký đếm lại từ đầu. Bản sửa đầu so `after > log_id`, nhưng node mới nhận đúng 10 dòng (giữ lại trên topic) nên `after = 10` không lớn hơn → không gửi gì | Server có mã phiên (`boot`), trình duyệt gửi kèm khi kết nối lại; khác phiên thì xoá và nhận lại toàn bộ |
  | 6 | Người làm đồ án thấy bản đồ trên web thiếu 2 pallet mà RViz có | Pallet cao 0.15 m, thấp hơn mặt quét lidar (0.17 m), nên không có trong `/map`; RViz vẽ chúng từ mặt nạ vùng cấm `/keepout_filter_mask` (bước 4), còn dashboard chỉ đọc `/map` | Dashboard đọc thêm mặt nạ, vẽ thành lớp đỏ trong suốt theo gốc tọa độ riêng của mặt nạ, thêm chú giải |

- **Kết quả** (mô phỏng headless, bấm nút trên dashboard, xem trên browser pane):
  - `giao_hang` 3/3 chặng, 66.0 s.
  - Chuỗi tự tạo (Kệ A1 lấy hàng → Khu nhận hàng trả hàng, chờ 2 s) 2/2 chặng, 36.4 s.
  - `giao_hang_2` (chạy bằng `curl` POST) 4/4 chặng, 72.4 s.
  - Bấm bản đồ → xe đi tới điểm đó; DỪNG giữa chặng → hai lần đọc vị trí cách nhau 3 s lệch nhau 0 mm.
  - Lệnh sai (`rm`, JSON sai, `cmd` không phải chuỗi, lệnh 1.8 kB) bị từ chối, path traversal → 404. `agv_cmd.py` vẫn dùng song song được.
  - Khởi động lại node giữa chừng → trang tự kết nối lại sau khoảng 2 s.
  - Chưa thử từ điện thoại thật qua Tailscale, chưa chạy trên Pi.
- **Bài học:**
  - Khi số đo của phần mới xấu bất thường, đo luôn phần cũ và một trường hợp rỗng để so; ở đây lỗi không nằm ở code mới.
  - Câu hỏi "nên làm A hay B" là xin ý kiến, không phải yêu cầu làm.

### 4.8. Giảm tải mô phỏng: bước vật lý 1 ms → 3 ms (PR #12)
- **Mục tiêu:** kiểm phát hiện ở mục 4.7: mỗi node Python dùng thời gian mô phỏng tốn 50–80 % một nhân CPU vì `/clock`. Xem đây có phải nguyên nhân của việc thỉnh thoảng khựng khoảng 1 s (vấn đề còn mở 1) không.
- **Cách làm:**
  - Theo bài học ở bước 3, xem các world mẫu chính thức trước khi tự chỉnh. Cả 3 world mẫu của Nav2 cài sẵn trong Jazzy (`nav2_minimal_tb3_sim/tb3_sandbox`, `nav2_minimal_tb4_sim/depot` và `warehouse`) đều dùng `max_step_size` **0.003 s**.
  - World của đồ án dùng 0.001 s, chỉ là giá trị có sẵn từ lúc dựng world, không có lý do ghi lại.
  - Gazebo phát `/clock` mỗi bước vật lý: 1000 tin/s với bước 1 ms, 333 tin/s với bước 3 ms. Các cảm biến (lidar 7 Hz, IMU 100 Hz, odom 30 Hz) đều chậm hơn nhiều so với 333 Hz.
- **Đo:**
  - Bài thử: nhiệm vụ `giao_hang` chạy tự động 2 lượt, headless.
  - Lấy mẫu `top` 10 s và RTF từ `/stats` của Gazebo.
  - Một node riêng so `/odom` (EKF) và `/amcl_pose` với `/ground_truth` theo thời gian của từng tin.
  - Hai cấu hình chạy xen kẽ trong cùng buổi (1 ms → 3 ms → 1 ms), để loại trừ khả năng máy tình cờ rảnh hơn ở một cấu hình.

  | | Bước 1 ms (5 lần, 30 chặng) | Bước 3 ms (4 lần, 24 chặng) |
  |---|---|---|
  | Chặng thành công | **9/30** (các lần: 2+0, 1+0, 0+0, 3+3, 0+0 trên 3+3) | **24/24** |
  | Một lượt `giao_hang` (khi thành công) | 61.6 – 69.8 s | 60.2 – 61.4 s |
  | RTF | 0.14 – 1.4, dao động mạnh | 0.99 – 1.01 (một lần có 2 mẫu 0.56, 0.65) |
  | Tổng CPU cả hệ thống mô phỏng | 670 – 808 % một nhân | 380 – 475 % |
  | Container Nav2 / EKF | 300 – 895 % / 17 – 111 % | 178 – 200 % / 14 – 16 % |
  | Mỗi node Python (`use_sim_time`) | 38 – 75 % | 30 – 48 % |
  | Cảnh báo "Control loop missed" | 11 – 152 mỗi lần | 0 – 1 |
  | Sai số odom EKF (cuối / quãng đường) | — | 0.20 m / 36.5 m (0.6 %) |
  | Sai số AMCL (90 % thời gian / lớn nhất) | — (PR #10: lớn nhất 0.14–0.16 m) | 0.062 / 0.080 m |

  Khi thất bại ở bước 1 ms, log báo TF `odom → base_footprint` trễ 0.5–4 s ("Lookup would require extrapolation into the future", "Transform data too old") và Nav2 huỷ đích. Đây chính là hiện tượng "khựng", nhưng nặng hơn nhiều so với hôm trước.
- **Sai lầm trong quá trình đo:**

  | # | Sai lầm | Phát hiện thế nào | Sửa |
  |---|---|---|---|
  | 1 | Kết luận lần đo 1 ms đầu tiên bị nhiễu vì "unattended-upgrades ăn 98 % CPU" | Đo riêng tiến trình đó: tổng cộng chỉ 0.09 s CPU từ lúc bật máy. Lệnh `awk` tách cột của `top` bị lệch | Rút lại kết luận; in nguyên dòng `top`, không tách cột |
  | 2 | Node đo báo odom sai 1.06 m, AMCL sai 0.91 m ở bước 3 ms, trong khi thời gian chặng vẫn y như cũ | Sai số gần như không đổi suốt lần chạy, giống độ lệch gốc toạ độ: node lấy mẫu `/ground_truth` đầu tiên làm gốc, mà node chỉ bật sau khi xe đã bắt đầu chạy | Lấy gốc là vị trí xuất phát đã biết (−4.5, 0), chạy lại cả hai cấu hình |
  | 3 | Một lần chạy 3 ms Nav2 không bao giờ sẵn sàng | Log: container nạp xong `map_server`, `amcl`, `controller_server` nhưng "failed to send response to /nav2_container/_container/load_node (timeout)", launch chờ mãi | Không liên quan tới bước vật lý; không tính vào bảng, ghi thành vấn đề còn mở |

- **Cách sửa:** `agv_gazebo/worlds/warehouse.sdf`: `max_step_size` 0.001 → 0.003, ghi lý do trong file.
- **Chưa kiểm lại:** các số đo của bước 1 (độ trôi odom bánh xe so với vị trí thật) chưa đo lại với bước 3 ms. Các số trên là odom sau EKF.
- **Bài học:**
  - Mặc định trong file mẫu (world 1 ms) cũng phải đối chiếu với dự án tham khảo như tham số thuật toán; một con số không ai chọn có thể quyết định cả hệ thống có quá tải hay không.
  - Kết quả lạ của công cụ đo (độ lệch không đổi, tiến trình "ăn" CPU) phải kiểm lại công cụ trước khi tin.

### 4.9. Kho kiểu Kiva, giai đoạn 1: chui gầm, nâng và chở kệ (PR #13)
- **Mục tiêu:** biến xe từ "đi tới điểm rồi đứng chờ" thành robot kho thật. Người làm đồ án chọn kiểu **Amazon Kiva**: xe chui gầm kệ mini, nâng kệ, chở cả kệ tới trạm lấy hàng (hàng tới người), tải 1–3 kg. Làm hết trong mô phỏng; khung Solid và PCB (chưa làm) sẽ theo kích thước của mô phỏng.
- **Thiết kế:**
  - **Lidar xuống giữa 2 tầng** (mặt quét 0.17 m → 0.12 m): trên nóc thì đáy kệ che lidar khi chui gầm. Hệ quả tốt: lidar thấy luôn pallet 15 cm, bỏ được vùng cấm vẽ tay ở mục 4.4.
  - **Mặt nâng** trên tầng 2: khớp trượt 0–3 cm, 2 cm/s (mô phỏng vít me), cảm biến tiếp xúc "có kệ". Giao diện topic `/lift/command`, `/lift/state`, `/lift/has_load` giữ nguyên cho cầu nối STM32 sau này.
  - **Kệ chở bằng vật lý thật** (kệ nằm trên mặt nâng nhờ ma sát), không dùng plugin `DetachableJoint`: plugin này gắn sẵn lúc khởi động (đọc world mẫu của Gazebo), mà kệ thì rải khắp kho.
  - **Kho:** 10 ô kệ (2 dãy × 5), 8 kệ, kệ cố định sát tường làm mốc cho AMCL. Một file `shelves.yaml` sinh ra world, danh sách dock của Nav2 và vùng cấm, để 3 nơi luôn khớp nhau.
  - **Chui gầm** bằng `docking_server` có sẵn của Nav2 Jazzy (loại `SimpleNonChargingDock`), mỗi ô là một dock.
  - Node `payload_manager` (dùng chung với xe thật): lọc scan (trụ ốc của xe; chân kệ khi chở), đổi footprint costmap theo tải, giới hạn tốc độ khi chở.
- **Bản đồ** lập lại 3 lần (mỗi lần đổi cỡ kệ): 100 % ô vật cản cách vật thật ≤ 10 cm, thấy 32/32 chân kệ. Lần cuối kém sắc hơn một chút (91.6 % ≤ 5 cm, trước đó 99.6–99.9 %), chưa rõ vì sao, vẫn dùng được.
- **Sự cố và cách tìm ra:**

  | # | Sự cố | Nguyên nhân (tìm bằng cách nào) | Cách sửa |
  |---|---|---|---|
  | 1 | Ra lệnh nâng, mặt nâng đứng yên ở 0 | Đẩy lệnh thẳng bằng `gz topic` vẫn không chạy → lỗi ở chế độ `use_velocity_commands` của `JointPositionController`; chế độ PID lực thì chạy | Dùng PID lực; `lift_sim` gửi quỹ đạo vị trí tăng dần 2 cm/s (vít me chạy đều bất kể tải), PID cứng + khâu I giữ được 3 kg |
  | 2 | Có PID lực nhưng nâng rất chậm (0.019 m sau 4 s) | Mặt nâng chạm đáy kệ sau 1.3 cm, lực P chỉ nhỉnh hơn trọng lượng kệ 29 N | Như trên |
  | 3 | `has_load` luôn False | Soi topic của Gazebo: cảm biến có báo chạm `deck_bottom` nhưng phát ở topic mặc định; với cảm biến contact, `<topic>` phải nằm **trong** `<contact>` | Chuyển thẻ `<topic>` |
  | 4 | Tên collision cho cảm biến sai | URDF → SDF thêm đuôi `_collision` (đọc SDF sinh ra bằng `gz sdf -p`) | Đặt tên URDF `lift_plate` |
  | 5 | Collision monitor sẽ bỏ hết điểm lidar | Đọc cấu hình: `min_height: 0.15` (mặc định Nav2), lidar mới ở 0.12 m | `min_height: 0.05` |
  | 6 | Chui gầm luôn báo "Collision detected" | Đọc mã nguồn `controller.cpp` của Jazzy: chỉ bỏ qua va chạm gần **đích** (= tâm dock lùi thêm 0.25 m); thứ "đụng" là vùng cấm của ô trong local costmap | Vùng cấm chỉ ở global costmap (để planner không xuyên gầm kệ); local costmap chỉ có vật cản lidar thấy |
  | 7 | Kệ 0.55 m: va chạm thật | Khe xe–chân kệ 5.5 cm; staging lệch ~8 cm ngang | Kệ 0.65 m rồi **0.75 m** (khe 15 cm; Kiva thật: kệ 0.9–1.2 m, xe 0.76 m), staging 1.0 m |
  | 8 | Tới staging lệch góc 24–51° | Quay tại chỗ với vùng chết (≥ 1.5 rad/s) vọt lố ~0.5 rad sau khi goal checker báo tới (14°) | Đi tới staging qua điểm xa hơn 1.2 m cùng trục ô → đoạn cuối thẳng (0.7 m chưa đủ: vẫn lệch 37°) |
  | 9 | Nâng kệ xong, lùi ra báo va chạm | Lúc còn hạ mặt nâng, 4 chân kệ đã vào costmap; sau khi nâng, điểm chân kệ bị lọc thành NaN, không tia nào xoá được → "chân kệ ma" trong footprint mới | `payload_manager` xoá costmap |
  | 10 | Vẫn lỗi như 9, lúc có lúc không | Xoá ngay khi **bắt đầu** nâng thì costmap vẫn giữ scan cuối chưa lọc và đánh dấu lại ngay | Xoá khi mặt nâng đã lên hết (`up`) |
  | 11 | Lùi ra khi chở: chân kệ lọt bộ lọc | Kệ nằm lệch trên mặt nâng ~7 cm (AMCL lệch lúc chui gầm), chân kệ ra tới 0.45 m, hộp lọc 0.41 m | Hộp lọc 0.48 m, footprint khi chở 0.84 m |
  | 12 | Ghi nhầm "docking tắt kiểm tra va chạm được" | Đọc launch của Nav2: `docking_server` phát thẳng `cmd_vel`, **không** qua collision monitor | Giữ kiểm tra va chạm của docking |

  Sai lầm của công cụ thử (cũng ghi lại vì đã làm mất thời gian): script chờ `amcl_pose` bằng QoS thường nên chờ mãi (AMCL phát kiểu giữ tin, chỉ khi xe chạy); khai báo tham số trong hàm gọi 2 lần nên crash; coi "có kết quả" là "thành công" nên một lần staging lệch 1.25 m vẫn báo OK; script không nạp profile Fast DDS nên node thử không thấy node khác; DiffDrive giữ lệnh cuối nên xe chạy mãi khi script quên gửi lệnh dừng.
- **Kết quả** (chu trình 10 bước: tới staging → chui gầm → nâng → lùi ra → chở tới trạm lấy hàng → tới staging → trả kệ → hạ → lùi ra → về trạm sạc; đo bằng vị trí thật; 6 lần mỗi cấu hình trên 3 kệ ở 2 dãy):

  | | Vùng chết 100 RPM (firmware hiện tại) | 50 RPM |
  |---|---|---|
  | Chu trình trọn vẹn | **6/6** | **6/6** |
  | Lệch góc tại staging (TB / lớn nhất) | 17.8° / 42.6° | 5.2° / 13.0° |
  | Lệch góc tại staging khi chở kệ | 33.3° / 66.3° | 8.5° / 13.6° |
  | Sau khi chui gầm lấy kệ (ngang / góc, lớn nhất) | 5.5 cm / 3.3° | 4.1 cm / 0.7° |
  | Kệ trả về lệch tâm ô | 3.1–8.7 cm | 0.6–5.6 cm |
  | Thời gian một chu trình | 74–107 s | 98–119 s |

  Trước các bản sửa cuối (kệ 0.75 m, xoá costmap khi `up`, hộp lọc 0.48 m), các lần chạy với kệ 0.55–0.65 m chỉ 1/3–2/3 chu trình xong.
- **Yêu cầu rút ra cho phần cứng:** khung theo kệ 0.75 × 0.75 m, gầm 0.18 m, xe cao ≤ 0.167 m khi hạ mặt nâng, lidar giữa 2 tầng; hạ `SPD_RPM_MIN` của firmware (đo ở trên: 50 RPM cho góc staging tốt hơn ~4 lần).
- **Bài học:**
  - Khi một thư viện báo "va chạm", đọc mã nguồn để biết nó coi cái gì là va chạm, đừng đoán.
  - Kích thước cơ khí phải chừa đủ cho sai số thật của định vị và điều khiển; thử bằng nhiều lần chạy, không tin một lần thành công.

### 4.10. Kho Kiva, giai đoạn 2: nhận diện kệ bằng chân kệ (PR #14)
- **Mục tiêu:** ở giai đoạn 1 xe chui gầm theo vị trí ô trên bản đồ (qua AMCL). Kệ trả về mỗi lần lệch 1–9 cm, lâu dần sẽ lệch nhiều; AMCL cũng lệch ~5 cm. Kiva thật dùng camera đọc mã dưới kệ; ở đây dùng **lidar nhìn 4 chân kệ**, không thêm phần cứng.
- **Cách làm:**
  - Node `shelf_detector.py`: trong `/scan_raw` (chưa lọc), gom điểm liên tiếp thành cụm, giữ cụm nhỏ (< 8 cm, chân kệ 3 cm), lùi tâm cụm thêm nửa bề rộng chân theo tia (lidar chỉ thấy mặt trước); tìm 4 cụm tạo hình vuông cạnh 0.72 m (2 điểm đối diện qua đường chéo → tính 2 đỉnh còn lại → tìm cụm gần); chọn kệ gần xe nhất phía trước. Hướng = trung bình 4 cạnh (nhân 4 để các cạnh lệch 90° trùng nhau).
  - Phát `/detected_dock_pose` với stamp **của scan**: `docking_server` so stamp này với giờ mô phỏng để tính timeout.
  - Đọc mã nguồn `SimpleNonChargingDock` của Jazzy trước khi cấu hình: mặc định `external_detection_translation_x = -0.2` và roll/pitch ±1.57 là cho camera đọc AprilTag, phải đặt về 0.
  - 2 loại dock: `shelf_dock` (lấy kệ, theo nhận diện) và `slot_dock` (trả kệ vào ô trống, không có chân để nhìn, theo bản đồ).
  - Bài thử thêm tham số `shelf_offset` (dời kệ bằng dịch vụ `set_pose` của Gazebo) và `detect` (chọn cách chui), đo sai số so với **kệ thật** chứ không so với ô.
- **Kết quả** (kệ dời lệch (+8, −6 cm, 4°), (−7, +5 cm, −5°), (+10, 0 cm, 0°), mỗi kiểu thử `ke_03` và `ke_06`, vùng chết 100 RPM):

  | | Chui theo chân kệ (`shelf_dock`) | Chui theo ô trên bản đồ (`slot_dock`) |
  |---|---|---|
  | Chui gầm lấy kệ thành công | **6/6** | 2/6 |
  | Chu trình trọn vẹn (10 bước) | **6/6** | 2/6 |
  | Lệch ngang so với kệ thật | **0.0–0.9 cm** | 1.6–10.9 cm |
  | Lệch góc so với kệ thật | 0.4–1.9° | 1.6–34.6° |
  | Lệch dọc so với tâm kệ (xe dừng quá) | 3.8–6.1 cm | 3.1–3.9 cm (2 lần chui được) |

  Theo bản đồ: 4/6 lần hỏng ở bước chui gầm, log `docking_server` báo "Collision detected" (xe vào đúng ô nhưng lệch kệ thật 9–11 cm, quỹ đạo quẹt chân kệ). Theo chân kệ: lệch ngang ≤ 0.9 cm dù kệ lệch ô tới 10.9 cm.
- **Sai lầm / sự cố:**

  | # | Sự cố | Nguyên nhân | Cách sửa |
  |---|---|---|---|
  | 1 | Loạt so sánh đầu mất hết kết quả (5/12 lần) | Log để ở `/tmp` của WSL; WSL tự khởi động lại (uptime về 0) và xoá `/tmp` | Log vào `~/agv_tests` (ext4), loạt thử chạy tách khỏi app (`nohup setsid`) |
  | 2 | Lần thử cmp10 hỏng khi khởi động | Trong lúc loạt thử chạy, đã sửa `mission.launch.py` để làm giai đoạn 3; workspace dùng `--symlink-install` nên launch đọc ngay file đang sửa, mà node mới chưa build | Cất phần giai đoạn 3 (`git stash`), chạy lại 3 lần cuối. Bài học: không sửa workspace đang được loạt thử dùng |
- **Còn lại:**
  - Xe dừng quá tâm kệ 4–6 cm theo chiều dọc ở mọi lần (đi ≥ 0.34 m/s do vùng chết, phanh muộn) → kệ nằm lệch tâm mặt nâng chừng đó. Có thể bù bằng `external_detection_translation_x`, hoặc hạ vùng chết (mục 4.9), chưa làm.
  - Trả kệ vẫn theo bản đồ (ô trống không có gì để nhận diện).
  - Bộ nhận diện thỉnh thoảng thấy "hình vuông" giả ở xa (ghép chân của các kệ / góc kệ cố định) nhưng luôn chọn kệ gần nhất phía trước nên chưa gây lỗi trong 12 lần thử.
- **Bài học:** đo sai số so với đúng đối tượng cần chạm tới (kệ thật), không so với vị trí "lẽ ra" của nó (ô trên bản đồ).

### 4.11. Kho Kiva, giai đoạn 3: quản lý đơn hàng (PR #15)
- **Mục tiêu:** thay "nhiệm vụ cố định" bằng **đơn hàng** như kho thật: tạo đơn "đưa kệ X tới trạm Y", hàng đợi có ưu tiên, người ở trạm xác nhận đã lấy hàng, lịch sử và thống kê.
- **Cách làm:**
  - Node `order_manager.py`: chạy đơn trong một luồng riêng, gọi các action của Nav2 (`NavigateThroughPoses` tới trước ô, `DockRobot`/`UndockRobot`, `NavigateToPose` tới trạm) và topic cơ cấu nâng; ROS spin bằng `MultiThreadedExecutor` ở luồng khác để luồng đơn hàng chờ được kết quả action.
  - Dữ liệu SQLite (thư viện chuẩn Python): bảng `orders` và `shelves` (kệ đang ở ô nào). Đơn đang chạy lúc tắt máy → đánh dấu lỗi khi khởi động lại.
  - Mỗi chặng thử lại 1 lần sau khi xoá costmap. Lỗi khi đang chở kệ → xe dừng, chờ người bấm "Đã xử lý" (xử lý tự động để giai đoạn 5).
  - Dashboard: thẻ *Đơn hàng* (tạo đơn, hàng đợi, nút xác nhận lấy hàng, lịch sử, thời gian TB); bản đồ vẽ từng kệ ở ô của nó, kệ đang chở vẽ theo xe. Lệnh đi qua `POST /api/command` với tiền tố `order`.
- **Kết quả** (mô phỏng, 2 lần, mỗi lần: 3 đơn `ke_03`, `ke_06` thường, `ke_01` gấp, thêm `ke_07` rồi huỷ; bài thử tự bấm xác nhận sau 3 s):

  | | Lần 1 | Lần 2 |
  |---|---|---|
  | Đơn xong / huỷ / lỗi | 3 / 1 / 0 | 3 / 1 / 0 |
  | Thứ tự chạy | ke_03 → **ke_01 (gấp)** → ke_06 | ke_03 → **ke_01 (gấp)** → ke_06 |
  | Thời gian mỗi đơn | 59–98 s | 76–111 s |
  | Kệ về ô lệch | 1.7–3.9 cm | 2.8–8.1 cm |
  | Chặng phải thử lại | 0 | 2 (chui gầm, lùi ra: "Collision detected"), thử lại đều qua |

  `ke_03` chạy đầu vì đơn của nó tạo trước khi các đơn kia vào hàng đợi.
- **Sai lầm / sự cố:**

  | # | Sự cố | Nguyên nhân | Cách sửa |
  |---|---|---|---|
  | 1 | Dashboard xếp hàng đợi theo số đơn, không theo thứ tự xe sẽ làm | `/order/state` lọc đơn chờ theo id | Sắp theo (ưu tiên giảm dần, id tăng dần) giống cách chọn đơn |
  | 2 | Lần chạy thử đầu không có log nào | Lệnh `wsl` thoát ngay sau `nohup setsid ... &`, tiến trình nền chưa kịp tách ra đã bị kết thúc cùng phiên | Đợi vài giây trước khi thoát `wsl` |
- **Còn lại:** chưa dừng khẩn / xử lý sự cố tự động (giai đoạn 5); chưa có pin và tự về sạc (giai đoạn 4); `order_manager` và `mission_server` chưa loại trừ nhau (dùng cùng lúc sẽ tranh điều khiển xe).
- **Bài học:** thử lại một lần sau khi xoá costmap gỡ được lỗi va chạm "ảo" thỉnh thoảng gặp; nhưng phải phân biệt lỗi trước và sau khi nâng kệ, vì khi đang chở thì không được tự bỏ đơn.

### 4.12. Kho Kiva, giai đoạn 4: pin và tự về sạc (PR #16)
- **Mục tiêu:** xe tự quản lý pin như AMR thật: rảnh thì vào sạc, pin yếu thì không nhận đơn mới, sạc đủ thì làm tiếp.
- **Cách làm:**
  - `battery_sim.py` phát `/battery_state` đúng kiểu ROS (`sensor_msgs/BatteryState`, dòng dương = đang sạc), cùng topic với INA226 trên xe thật. Sạc khi xe (vị trí thật) cách điểm dock ≤ 6 cm, lệch góc ≤ 0.2 rad.
  - Trạm sạc là dock `SimpleChargingDock` có sẵn của Nav2, sinh trong danh sách dock từ `stations.yaml`. Đọc mã nguồn plugin trước: "đang sạc" = dòng > `charging_threshold`.
  - `order_manager`: rảnh → vào sạc; ngưỡng nhận đơn = `battery_low` + `order_reserve`; có đơn khi đang ở trạm và pin đủ → rời trạm rồi làm.
- **Sai lầm / sự cố** (mỗi lần sửa đều chạy lại bài thử pin):

  | # | Sự cố | Nguyên nhân (tìm bằng cách nào) | Cách sửa |
  |---|---|---|---|
  | 1 | `simple_charging_dock` trong file mẫu bật `use_external_detection_pose` | Đọc cấu hình: nó sẽ đọc `/detected_dock_pose` của `shelf_detector` → xe chui vào kệ thay vì vào trạm sạc | Tắt, trạm sạc theo bản đồ |
  | 2 | Cả 3 đơn hỏng "Failed initial dock detection"; bài thử vận chuyển cũ cũng hỏng, staging lệch ngang **5 m** | Khối tiếp điểm (cao 8 cm, cố ý thấp hơn lidar để bản đồ khỏi đổi) đặt ngay trước chỗ xe xuất phát: Nav2 lập đường xuyên qua nó, xe húc vào, bánh trượt nhưng odom vẫn tăng, AMCL tưởng xe đã tới staging. Giống hệt sự cố pallet ở mục 4.4 | Dời trạm sạc ra sau chỗ xuất phát 0.45 m (xe tiến về phía tây vào sạc), khối cao 0.15 m để lidar thấy, lập lại bản đồ |
  | 3 | Nhận đơn lúc pin 34 % (trên ngưỡng 30 %) rồi cạn 0 % giữa đơn | Chỉ so với ngưỡng, không tính phần pin cho chính đơn đó | Thêm `order_reserve` (10 %) |
  | 4 | 2 đơn hỏng ngay khi khởi động | Chỉ chờ action server của docking xuất hiện, chưa chờ Nav2 "active"; và còn 2 đơn "đang chờ" của lần thử trước trong SQLite | Chờ `bt_navigator` + `docking_server` active (như `mission_server`); mô phỏng (`reset_shelves`) huỷ đơn cũ |
  | 5 | Rời trạm thất bại mãi: "Robot is not in the dock" | Xe bật khỏi tiếp điểm > `docking_threshold` 5 cm | Nếu `UndockRobot` lỗi thì lùi thẳng 0.5 m bằng behavior `BackUp` (quay tại chỗ sát khối sẽ quét vào nó) |
  | 6 | Vào trạm sạc báo va chạm, xe chui chéo | Xe trong vòng 0.5 m quanh staging thì `docking_server` bỏ qua bước tới staging; lúc khởi động xe đứng ngay đó, quay lưng về trạm | Tự đi thẳng vào staging dọc trục trạm rồi mới `DockRobot` (như với kệ) |
  | 7 | Vẫn báo va chạm khi xe chỉ còn cách dock 3–7 cm, trên trục | Bản thân khối tiếp điểm (lidar thấy) nằm ngay rìa vùng bỏ qua va chạm 0.3 m quanh đích | `dock_collision_threshold: 0.45`; kiểm lại: các lần chui gầm kệ vẫn qua |
- **Kết quả** (pin đầu 45 %, hao / sạc nhanh gấp 8, 3 đơn, bài thử tự bấm xác nhận):
  - 3/3 đơn xong (77, 70, 57 s).
  - Sau đơn 1 pin 30.3 % < 40 % → dừng nhận đơn, vào trạm ngay lần đầu, sạc 28.3 → 80.4 % trong 187 s (mô phỏng), rời trạm làm đơn 2, 3; hết đơn thì về sạc.
  - Chỉ có 1 lần chạy đạt sau các bản sửa; trước đó 5 lần thử lộ 7 sự cố ở bảng trên.
- **Còn lại:** chưa xử lý pin cạn giữa đơn (pin mô phỏng xuống 0 % vẫn chạy); vị trí tiếp điểm dựa vào AMCL (±5 cm), xe thật cần tiếp điểm lò xo đủ rộng hoặc nhận diện trạm sạc.
- **Bài học:** vật cản thật mà cảm biến không thấy là nguy hiểm, kể cả khi "cố ý" làm vậy để bản đồ khỏi đổi; sửa bản đồ rẻ hơn nhiều so với tìm ra vì sao xe "đi" 5 m mà vẫn đứng yên.

### 4.13. Kho Kiva, giai đoạn 5: xử lý sự cố (PR #17)
- **Mục tiêu:** xe không được "chết lặng" hay tự làm điều nguy hiểm khi có sự cố: dừng đúng lúc, báo cho người, và làm tiếp đúng chỗ sau khi người xử lý xong.
- **Cách làm** (trong `order_manager`):
  - Đơn hàng là danh sách bước có chỉ số; sự cố "tiếp tục được" (dừng khẩn, đường bị chặn, lỗi một bước khi đang chở) → chờ người bấm "Đã xử lý" (`ack`) rồi **làm lại đúng bước đang dở**. Sự cố "không tiếp tục được" (rơi kệ, cơ cấu nâng lỗi) → đơn lỗi, kệ "chưa rõ vị trí" cho tới khi người cập nhật (`shelf <kệ> <ô>`).
  - Giám sát 5 Hz: mất tín hiệu "có kệ" > 1 s khi đang chở, cơ cấu nâng báo lỗi. Khi có sự cố: huỷ mọi goal Nav2 / docking đang chạy, gửi vận tốc 0.
  - Đường bị chặn: theo dõi feedback của Nav2 (`number_of_recoveries`, `distance_remaining`): Nav2 bắt đầu tự hồi phục hoặc không tiến về đích > 15 s → cảnh báo; > 60 s (hoặc chặng lỗi hẳn sau khi thử lại) → sự cố chờ người dọn đường.
  - Lỗi trước khi nâng kệ → trả đơn về hàng đợi (tối đa 2 lần).
  - Dashboard: nút **DỪNG KHẨN**, dải cảnh báo vàng, dải sự cố đỏ + nút "Đã xử lý".
  - Bài thử `fault_test.py` gây sự cố có chủ ý trong lúc xe đang chở kệ: dựng tường chắn ngang kho bằng dịch vụ `create` của Gazebo (rồi gỡ), gửi dừng khẩn, dịch kệ ra khỏi xe bằng `set_pose`.
- **Sai lầm / sự cố khi làm** (10 lần chạy bài thử sự cố + 4 lần thử đơn hàng bình thường):

  | # | Sự cố | Nguyên nhân (tìm bằng cách nào) | Cách sửa |
  |---|---|---|---|
  | 1 | Không đơn nào chạy | Log: luồng xử lý đơn chết vì `unhashable type: 'ClientGoalHandle'` (giữ goal handle trong `set`) | Dùng `list` |
  | 2 | Tường chắn 25 s mà không có cảnh báo nào, đơn vẫn xong (chặng dài 20 → 48 s) | Log Nav2: không có lỗi hay hồi phục; lidar chỉ thấy từng đoạn tường, planner liên tục vạch đường vòng qua phần chưa thấy → Nav2 "đang đi" chứ không lỗi | Theo dõi tiến độ `distance_remaining` (không tiến > 15 s → cảnh báo, > 60 s → sự cố), cộng số lần hồi phục |
  | 3 | Bước lùi ra (đang đội kệ) lỗi thì đơn bị **trả về hàng đợi và chạy lại từ đầu** — xe đội kệ đi tới staging, Nav2 hồi phục 31 lần | Phân loại sai: coi mọi `OrderError` là "lỗi trước khi nâng kệ" | Lỗi bất kỳ khi đang chở → sự cố chờ người, làm lại đúng bước đó; thêm chờ 1.5 s sau khi nâng cho costmap cập nhật |
  | 4 | Một số chỗ ném sự cố mà không ghi trạng thái → "Đã xử lý" không được nhận, xe chờ mãi | Đọc lại code: `ack` chỉ nhận khi `self.fault` có giá trị | Mọi sự cố đi qua `trigger_fault` |
  | 5 | Kết quả bài thử lộn xộn (đơn lạ, dừng khẩn sai lúc) | Bài thử cũ vẫn chạy và gửi lệnh vào mô phỏng mới (cùng domain); script dọn dẹp quên giết `fault_test.py` | Dọn dẹp giết mọi script thử |
  | 6 | Bài thử "đường bị chặn" chờ nhau với xe | Sự cố tới sau 75 s (Nav2 hồi phục + thử lại + chờ 60 s) mà kịch bản chỉ bấm "Đã xử lý" đúng một lần lúc gỡ tường | Kịch bản thấy sự cố lúc nào thì bấm lúc đó |
  | 7 | Chạy lại bài thử đơn hàng bình thường: 1 đơn trả kệ vào ô S2 lỗi 2 lần, xe dừng chờ người | Log docking: va chạm khi xe (đang chở) lệch ~0.3 m vào ô — footprint vuông 0.84 m chạm chân kệ ô S1 bên cạnh (khe chỉ ~17 cm mỗi bên). Footprint vuông đặt từ giai đoạn 1 cho kệ lệch 7 cm mọi hướng; từ giai đoạn 2 kệ chỉ lệch theo chiều dọc | Footprint khi chở hình chữ nhật: dọc ±0.44 m, ngang ±0.39 m |
  | 8 | Xe kẹt sát khối trạm sạc 60 s ngay đơn đầu | Vào trạm sạc lỗi rồi nhận đơn đi luôn từ chỗ sát khối, quay tại chỗ quẹt vào khối (bộ phát hiện kẹt báo đúng) | Vào trạm lỗi thì lùi thẳng 0.5 m trước |
  | 9 | Báo "không tiến về đích 15 s" cả khi xe chạy bình thường | `distance_remaining` của `NavigateThroughPoses` không giảm đều (có lúc 0) | Tự tính khoảng cách thẳng từ `current_pose` (feedback) tới đích cuối |
  | 10 | Lùi ra sau khi **đã hạ kệ** lỗi thì đơn bị trả về hàng đợi, xe quay lại nâng chính kệ đó | Quy tắc "chỉ trả đơn khi chưa chở" sai: sau khi hạ, xe không chở nhưng vẫn đang ở gầm kệ | Từ bước nâng kệ trở đi mọi lỗi thành sự cố chờ người; lùi ra lỗi thì lùi thẳng 1 m bằng `BackUp` |
  | 11 | Người dùng mở mô phỏng có GUI: xe **tự chạy lòng vòng quanh trạm sạc** ~100 s ngay khi mở | Log `docking_server`: "Timed out approaching dock", hết lượt thử. Xe xuất phát ở gốc bản đồ quay lưng về trạm sạc; `order_manager` lúc khởi động gọi về sạc, mỗi lần vào trạm lỗi lại lùi ra rồi đi vòng vào lại. Các bài thử headless không thấy vì chỉ nhìn kết quả đơn | Xe xuất phát ngay ở trạm sạc (launch `x/y/yaw:=auto`, AMCL `initial_pose` tại trạm); đang sạc sẵn thì bỏ bước đi tới staging. Log sau sửa: "Robot is already docked and/or charging, no need to dock" |
- **Kết quả** (tất cả sự cố gây ra trong lúc xe đang chở kệ tới trạm). Hai lần chạy cuối:

  | Tình huống | Kết quả |
  |---|---|
  | Tường chắn ngang kho 75 s | lần f7: cảnh báo → sự cố `duong_bi_chan` → gỡ tường + "Đã xử lý" → đơn **xong** (155.7 s). Lần f10 (sau khi đổi cách đo tiến độ): cảnh báo, nhưng **chưa thành sự cố** trước khi gỡ tường (xe men theo tường về phía đích nên vẫn "tiến"), đơn xong — bài thử tính là **SAI** theo tiêu chí đặt trước |
  | Dừng khẩn | xe đi thêm **0.0 cm** trong 3 s sau khi dừng; "Đã xử lý" → làm tiếp bước đang dở, đơn **xong** |
  | Dịch kệ ra khỏi xe | phát hiện sau **1.7 s**, xe dừng, đơn lỗi, kệ "chưa rõ vị trí"; `shelf ke_02 N5` cập nhật đúng |
  | Chạy đơn bình thường sau khi thêm xử lý sự cố | lần o8: **3/3** đơn xong (70–119 s), đơn gấp trước, đơn huỷ không chạy, kệ về ô lệch 5.0–9.7 cm |
  | Chạy đơn bình thường, xe xuất phát ở trạm sạc (sau sửa #11) | lần o9: **3/3** đơn xong (81–105 s), đơn huỷ không chạy, kệ về ô lệch 5.4–13.3 cm |
- **Chưa làm:** mất định vị (AMCL lạc) chưa phát hiện tự động; mất liên lạc với STM32 (sẽ do cầu nối UART + watchdog của firmware lo); pin cạn giữa đơn.
- **Bài học:** "Nav2 không báo lỗi" không có nghĩa là xe đang tiến tới đích — phải đo tiến độ; và mọi quyết định khi xe đang mang hàng phải tính tới trạng thái vật lý (đang đội kệ), không chỉ trạng thái phần mềm.

### 4.14. Xe "vòng vòng", trả kệ lệch 50°: vùng chết động cơ (PR #17)
- **Phát hiện:** người dùng chạy mô phỏng có GUI và thấy hai chuyện. (1) Một đơn dừng với sự cố "lùi ra thất bại (xe còn ở gầm ke_05)": theo Gazebo, kệ nằm trong ô S1 nhưng **xoay 37°**, còn xe lệch hướng 50° so với trục ô và cách kệ 0.53 m. (2) Nhiều lúc xe "quyết định không dứt khoát", quay vòng vòng.
- **Cách tìm nguyên nhân:**
  - Log `docking_server` của lần (1): khi trả kệ, docking báo "Collision detected" 2 lần, mỗi lần quay về staging rồi vào lại; lần 3 thì "Docking was successful". Bộ docking chỉ kiểm **khoảng cách** tới tâm ô (`docking_threshold`), không kiểm hướng. Vì vậy xe tới tâm ô khi đang lệch 50° vẫn được tính là xong, `order_manager` hạ kệ luôn. Sau đó xe lùi ra theo hướng lệch, đi chéo về phía đông bắc và chạm chân kệ ô S2 ("Collision Ahead").
  - Viết bài thử mới `agv_gazebo/scripts/motion_test.py`. Bài thử chạy 8 đơn liên tiếp, ghi vị trí thật (`/ground_truth`) 20 Hz theo từng bước của đơn. Mỗi bước tính: tổng góc quay, **góc quay thừa** (tổng trừ góc thực sự cần quay), số lần đảo chiều quay, và tư thế xe ngay trước khi hạ kệ.
  - Chạy cùng một code hai lần: có vùng chết động cơ (như xe thật) và tắt vùng chết (`rpm_min:=0`).

  | Góc quay thừa (TB / lớn nhất) | Có vùng chết (m1) | Tắt vùng chết (m2) |
  |---|---|---|
  | Chui gầm lấy kệ | 627° / **4261°** | 4° / 8° |
  | Trả kệ vào ô | 762° / **4198°** | 0° / 1° |
  | Tới staging | 293° / 454° | 227° / 246° |
  | Từ trạm về staging (đang chở) | 519° / 821° | 188° / 201° |

  Vùng chết của động cơ là nguyên nhân chính. Firmware ép mọi lệnh khác 0 lên ≥ 100 RPM, nên xe không đi chậm hơn 0.34 m/s và không quay chậm hơn 1.5 rad/s (mục 4.9). Đọc quỹ đạo từng bước thì có **ba cơ chế** riêng:
  1. **Quay tròn tại staging khi docking thử lại.** Mỗi lần thử lại, docking lùi xe về staging. Nó chỉ dừng khi xe vừa nằm trong 5 cm vừa đúng hướng trong 6° (`undock_linear/angular_tolerance` 0.05 / 0.1). Với bước quay tối thiểu 1.5 rad/s thì gần như không đạt được: xe quay hết vòng này tới vòng khác 8–15 s mỗi lần (đơn #2 lần m1: 60 s, quay 4270°, 29 lần đảo chiều).
  2. **Vọt lố sau mỗi lần quay tại chỗ.** Lệnh quay đi qua `velocity_smoother`, bộ này hạ lệnh dừng từ từ (3.2 rad/s²). Mọi giá trị khác 0 trên đường hạ đều bị vùng chết đẩy lại lên 1.5 rad/s, nên xe quay hết tốc cho tới khi lệnh về đúng 0. Đo: mỗi lệnh Spin quay thừa khoảng 30–80°.
  3. **Đi vòng tròn quanh đường gần đích.** Regulated Pure Pursuit giảm tốc khi gần đích, xuống tới 0.05 m/s (`min_approach_linear_velocity`). Khâu giữ bán kính cua (`motor_model`, mục 4.9) đẩy cả hai bánh lên cùng tỉ lệ cho tới khi bánh chậm nhất đạt 100 RPM. Vì vậy lệnh "0.05 m/s + bẻ lái nhẹ" thành 0.34 m/s và tốc độ bẻ lái gấp 7 lần: vòng điều khiển (có trễ) vọt lố, xe đi vòng tròn quanh điểm đích.
  - **Đoán sai trong lúc tìm:**
    - (a) Nghĩ kệ trượt trên mặt nâng khi xe quay nhanh. Lần đo đầu cho "kệ lệch so với xe 40 cm, 42°", nhưng đó là do lệnh `gz model` mất khoảng 1 s nên lấy vị trí kệ và xe ở hai thời điểm khác nhau. Đo lại lúc xe đứng yên ở trạm: kệ lệch 4–10 cm, xoay tới 11–23° so với xe. Phần lớn là do lúc chui gầm xe đã lệch, nhưng có ít nhất một lần kệ bị coi là rơi khi đang lùi (lần m3).
    - (b) Nghĩ cách "dừng, quay tại chỗ cho thẳng trục ô, rồi đi thẳng" (kiểu Kiva) sẽ dứt khoát hơn. Thực tế bộ quay tại chỗ không thể chỉnh góc nhỏ: xin quay 3° thì xe quay 40°, xin 11° thì quay 36° (lần s2, sau khi đã sửa smoother). Xe lắc qua lắc lại 8–12 lần rồi báo lỗi. Bỏ phương án này và phương án đi thẳng vào ô bằng `DriveOnHeading` (cần quay chỉnh chính xác trước).
    - (c) Đặt tốc độ docking bằng tốc độ thật (0.35 m/s) để bộ điều khiển "biết" xe chạy nhanh thế nào. Kết quả: quỹ đạo dự báo cua rộng hơn và quét chân kệ, docking báo va chạm 4/4 lần, xe kẹt sát chân kệ, planner không lập được đường (lần m4). Trả về 0.15.
- **Cách sửa (giữ):**
  - `nav2.yaml`:
    - `undock_linear/angular_tolerance` 0.10 m / 0.3 rad, để docking khi thử lại không phải quay tròn tìm đúng hướng.
    - `velocity_smoother` gần như bỏ giới hạn gia tốc (5 m/s², 20 rad/s²). Giới hạn thật đã do động cơ (DiffDrive 1 m/s², 3 rad/s²) đảm nhận.
    - RPP không bao giờ xin chậm hơn mức bánh chạy được: `min_approach_linear_velocity` và `regulated_linear_scaling_min_speed` 0.35, `rotate_to_heading_angular_vel` 1.5.
    - `behavior_server` 20 Hz.
  - `order_manager.checked_dock()`: sau khi chui gầm (trước khi nâng) và sau khi trả kệ (trước khi hạ), lấy tư thế xe từ TF `map → base_link` và so với trục ô. Nếu lệch hướng > 8°, hoặc khi trả kệ lệch vị trí > 10 cm, thì lùi thẳng ra staging rồi vào lại, tối đa 3 lần. Lệch > 40° thì quay tại chỗ bớt trước khi lùi (xin bớt 30° vì phần quay thừa). Ở giữa ô quay vẫn an toàn: nửa đường chéo kệ 0.53 m, chân kệ ô bên cạnh cách tâm ô ≥ 0.82 m.
  - Mô phỏng: khi nâng hết thì khoá kệ vào mặt nâng bằng khớp cố định (plugin `DetachableJoint` sinh trong mỗi kệ của world), hạ kệ thì mở khoá trước. Việc này tương ứng với chốt định vị trên mặt nâng của xe thật. Khi chỉ nhờ ma sát, chân kệ có thể lọt ra ngoài vùng lọc scan và thành "vật cản" sát xe. Plugin tự nối khớp mọi kệ với xe lúc mô phỏng bắt đầu, nên `lift_sim` mở khoá hết khi thấy xe. Lần đầu mở khoá lần lượt 8 kệ × 2 lần mất 16 s: xe đã nhận đơn và chạy khi vài kệ còn dính vào xe (lần s1), nên đổi sang gọi song song.
- **Sai lầm của công cụ thử:**
  - Một lần chạy bị hỏng vì `motion_test.py` của lần trước vẫn chạy: script dọn dẹp không giết nó, nên mỗi đơn được thêm 2 lần. Đã thêm vào script dọn dẹp.
  - Một lần sửa script bằng chuỗi có `\n` sinh ra lỗi cú pháp làm hỏng một lần chạy.
- **Kết quả** (8 đơn liên tiếp, có vùng chết; m1 = trước, m7 = sau khi sửa):

  | | m1 | m7 |
  |---|---|---|
  | Đơn xong | 8/8 | 8/8 |
  | Thời gian TB / đơn | 105 s (87–146) | 88 s (63–103) |
  | Nav2 tự hồi phục | 6 lần ở đơn #2, 4 lần ở #8… | 0 |
  | Quay thừa khi chui gầm (TB / max) | 627° / 4261° | 168° / 1251° |
  | Quay thừa khi trả kệ (TB / max) | 762° / 4198° | 28° / 75° |
  | Quay thừa trạm → staging (TB / max) | 519° / 821° | 228° / 390° |
  | Lệch hướng xe khi trả kệ (max, vị trí thật) | 3.2° | 4.1° |
  | Kệ sau đơn: lệch tâm / xoay (max) | 8.6 cm / 10.1° | 8.7 cm / 5.5° |

  - Kiểm tra tư thế đã bắt được một lần chui gầm lệch (ô N1) và vào lại đạt ở lần 2. Lần m5 (trước khi bỏ phương án (b)) tái hiện đúng lỗi của người dùng: docking trả kệ báo xong khi xe lệch +49°, và bước kiểm tra đã chặn không cho hạ kệ.
  - Bài thử sự cố chạy lại sau khi sửa (f11): **3/3 đạt**. Kịch bản "rơi kệ" giờ phải mở khoá trước, như khi chốt định vị bị gãy.
- **Còn lại:** tới staging vẫn quay thừa khoảng 300° (TB) vì đường đi qua điểm trước staging có góc gấp. Một lần chui gầm vẫn quay thừa 1251° (lần thử lại của docking). Gốc rễ là vùng chết, cách sửa thật nằm ở firmware (mục 6).
- **Bài học:** khi bộ chấp hành có vùng chết, mọi khâu "lệnh nhỏ dần về 0" (giảm tốc gần đích, làm mượt vận tốc, dung sai hẹp) đều biến thành vọt lố. Phải đo quỹ đạo thật theo từng bước thay vì chỉ nhìn đơn có xong không, vì 8/8 đơn xong vẫn che được một bước quay 4000°.

### 4.15. Lidar lệch bản đồ khi xe đứng yên; cửa sổ Gazebo không mở (PR #17)
- **Phát hiện:** người dùng chụp RViz: các chấm lidar lệch khỏi tường trên bản đồ. Lỗi cũ thứ hai: chạy `sim.launch.py nav:=true` thì cửa sổ Gazebo đôi khi không mở.
- **Lidar lệch: tìm nguyên nhân.**
  - So vị trí AMCL (TF `map → base_link`) với vị trí thật trên chính mô phỏng đang chạy: xe đứng yên ở trạm sạc nhưng localization lệch **30.8 cm, −11.2°**. Góc odom vẫn tăng đều (−18.7° → −19.0° trong 16 s) dù xe không chạy.
  - Đo vận tốc quay khi đứng yên: odom bánh = 0, IMU −0.000464 rad/s, EKF −0.000409 rad/s. IMU mô phỏng được cấu hình có bias con quay (`bias_mean` 0.0005 rad/s, cố ý giống IMU thật), và EKF cộng bias này vào góc yaw. AMCL chỉ cập nhật khi odom đổi quá `update_min_a`/`update_min_d`, nên khi xe đứng yên bản đồ và lidar lệch dần.
  - **Đoán sai và các lần sửa bỏ đi:**
    1. Khi hai bánh đứng yên, đặt phương sai tốc độ quay của odom bánh rất nhỏ (1e-6, rồi 1e-9), với lập luận xe skid-steer không thể quay khi bánh không lăn. Không có tác dụng: vận tốc quay của EKF chỉ giảm một nửa (0.000207 so với IMU 0.000474), góc vẫn trôi ~1.3°/phút. Nguyên nhân: giữa hai tin odom bánh (20 Hz), nhiễu quá trình của EKF làm phương sai tăng lại, và các tin IMU (71 Hz) lại kéo trạng thái theo.
    2. Hạ `update_min_a` của AMCL từ 0.2 xuống 0.05 rad, để lidar sửa lại mỗi khi odom trôi 3°. Không có tác dụng: đứng yên 10 phút thì odom trôi −24.4° và AMCL lệch −24.7°, không sửa chút nào. AMCL tin odom rất cao (`alpha` 0.05, mục 4.6), nên các hạt quay theo odom và lidar không kéo lại được. Đã trả về 0.2.
- **Lidar lệch: cách sửa.** Node mới `agv_localization/imu_bias.py`, dùng chung cho mô phỏng và xe thật: `/imu/raw → /imu`. Khi `/wheel/odom` báo bánh đứng yên quá 1 s, mọi tốc độ quay con quay đo được đều là bias. Node lấy trung bình trượt (hằng số thời gian 5 s) và trừ vào mọi mẫu. Bridge mô phỏng đổi `/imu` thành `/imu/raw`; cầu nối IMU của xe thật cũng phải phát `/imu/raw`.

  | Xe đứng yên ở trạm sạc | Odom yaw trôi | Localization lệch |
  |---|---|---|
  | Trước (i3, 300 s) | −2.39° (bias mỗi lần chạy khác nhau) | −2.5° |
  | Trước (i4, 600 s) | **−24.4°** | **−24.7°** |
  | Sau (i5, 300 s) | **+0.05°** | −0.2° |

  Chạy lại 8 đơn (m9): 8/8 xong, TB 88 s. Localization (TF) khi xe chạy lệch lớn nhất 13 cm, phần lớn ≤ 10 cm.
- **Sai lầm của công cụ đo:** ở mục 4.14, "AMCL sai max" ~0.3 m được coi là do `/amcl_pose` phát tin cũ, nhưng khi đó chưa kiểm chứng. Đã đổi `motion_test.py` sang đo bằng TF; khi xe chạy, sai số thật ≤ 13 cm.
- **Sự cố phát sinh khi sửa (khoá kệ của mục 4.14):**
  - Một lần chạy (m8) xe hoàn toàn không đi được. Vị trí thật đứng yên, còn odom tưởng xe đã lùi 1.5 m: bánh quay trượt vì xe vẫn còn dính vào 8 kệ. Lệnh mở khoá gửi một lần bằng `gz topic -p` có thể bị mất khi chưa kịp kết nối với plugin; lần m7 chạy được là do may.
  - Sửa: `lift_sim` dùng publisher gz-transport thường trực (Python `gz.transport13`), đọc trạng thái thật của khớp `/shelf/<kệ>/state`, và mỗi giây gửi lại cho tới khi khớp. Lệnh khoá chỉ được gửi trong 3 s sau khi nâng, để không tự khoá lại một kệ đã bị gỡ (bài thử rơi kệ).
  - Một lần (s3) xe vẫn không rời được trạm sạc dù các khớp đã báo `detached`: docking và BackUp báo vật cản ngay sau xe. Chạy lại không gặp lại. **Chưa tìm ra nguyên nhân.**
  - Lần s4: hạ kệ xong mặt nâng dừng ở 2.0 mm, đúng bằng dung sai 0.002 m, nên phép so sánh không đạt và sau 5 s báo "cơ cấu nâng lỗi". Đã nới dung sai lên 4 mm (hành trình 30 mm).
- **Cửa sổ Gazebo:**
  - Tái hiện 4 lần chạy đầy đủ: cửa sổ chết **1/4 lần** (exit 139). Backtrace: segfault trong driver NVIDIA D3D12 của WSL (`driCreateNewScreen` → `libnvwgf2umx.so`) lúc tạo màn hình OpenGL, khi RViz cũng đang khởi tạo. Mở tay sau đó thì chạy bình thường.
  - Đây là lỗi driver, không sửa được trong dự án. Launch giờ chạy thẳng `gz sim -g` trong một vòng lặp: chết vì segfault thì mở lại sau 3 s, tối đa 4 lần; người dùng tự đóng cửa sổ thì không mở lại. Thử 3 lần: một lần cửa sổ crash rồi tự mở lại được.
- **Bài thử sự cố sau khi sửa (f12): 2/3.** Dừng khẩn và rơi kệ đạt. Tường chắn: có cảnh báo nhưng chưa thành sự cố trước khi gỡ tường (giống f10, vì xe men theo tường nên vẫn được tính là "đang tiến").
- **Bài học:** mô phỏng có nhiễu và bias giống thật thì phải có bước bù giống thật (hiệu chỉnh bias con quay khi đứng yên). Và trước khi chỉnh tham số theo một giả thuyết, đo xem đại lượng trung gian (ở đây là vận tốc quay của EKF) có đổi đúng như dự đoán không.
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

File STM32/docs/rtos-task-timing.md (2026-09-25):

# Sơ đồ thời gian các task FreeRTOS

Tài liệu mô tả các task chạy trên STM32F407 theo thời gian, lấy từ code hiện tại
(`App/Src/app.c`, `Core/Src/freertos.c`, `Core/Inc/FreeRTOSConfig.h`). Cuối file
có sẵn một prompt để đưa cho công cụ AI vẽ sơ đồ.

> Các con số thời gian thực thi của `controlTask` là **ước lượng**. Số liệu thật cần
> đo bằng cách bật/tắt một chân GPIO ở đầu và cuối task rồi xem bằng logic analyzer.

## 1. Thông số hệ thống
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

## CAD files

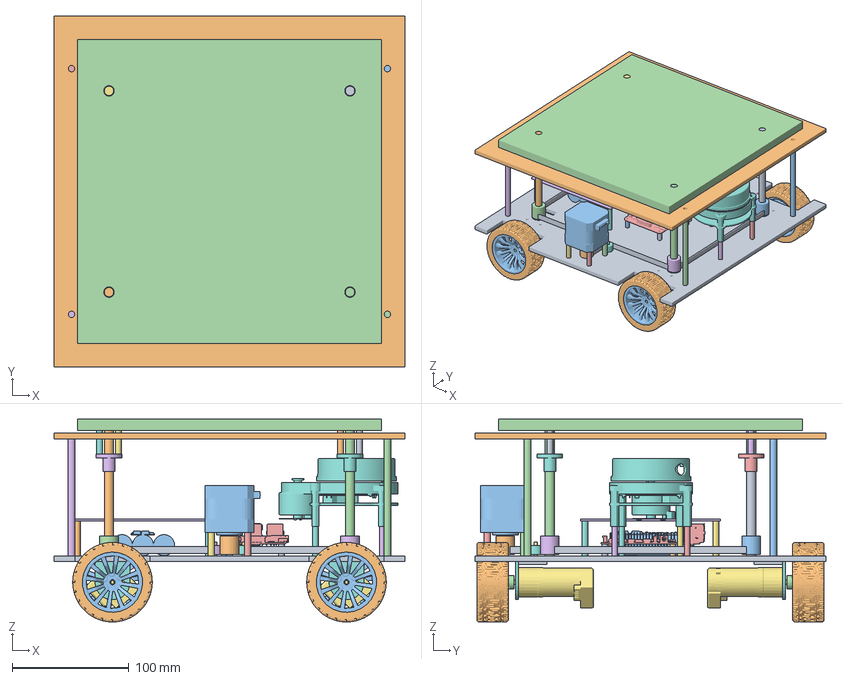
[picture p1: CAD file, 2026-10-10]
CAD/agv.FCStd
300.0 x 300.0 x 173.5 mm
Tang 1 (mica)
Tang 2 (mica)
Tru oc 1
Tru oc 2
Tru oc 3
Tru oc 4
GA25-370 + encoder (STEP GrabCAD) x 4
Ga L - mat bat dong co x 4
Ga L - de bat len mica x 4
Lop banh 68 mm (STEP GrabCAD) x 4
Mam banh (STEP GrabCAD) x 4
Khop noi luc giac 12 mm (STEP, lo 3 mm) x 4
Tru do lidar 1
Tru do lidar 2
Tru do lidar 3
Tru do lidar 4
Tru do Pi 1
Tru do Pi 2
Tru do Pi 3
Tru do Pi 4
Raspberry Pi 4B (STEP GrabCAD)
PCB (hinh chu nhat giu cho)
Tru do PCB 1
Tru do PCB 2
Tru do PCB 3
Tru do PCB 4
Pin 3S 18650 + BMS (STEP GrabCAD)
Mat nang 260 x 260 (4 lo dau vit)
Dai oc dong T8 1
Tru dong M3x20 1a
Tru dong M3x20 1b
Dai oc dong T8 2
Tru dong M3x20 2a
Tru dong M3x20 2b
Dai oc dong T8 3
Tru dong M3x20 3a
Tru dong M3x20 3b
Dai oc dong T8 4
Tru dong M3x20 4a
Tru dong M3x20 4b
Vit me T8 1
O bi F688 1
Puly GT2 20T 1
Vit me T8 2
O bi F688 2
Puly GT2 20T 2
Vit me T8 3
O bi F688 3
Puly GT2 20T 3
Vit me T8 4
O bi F688 4
Puly GT2 20T 4
Truc con lan 1
Con lan ep dai 1
Truc con lan 2
Con lan ep dai 2
Dai GT2 6 mm kin ~860 mm (khong tu cap nhat theo Params)
Puly GT2 20T lo 5 mm (dong co)
Dong co buoc NEMA17 42 x 42 x 40 (STEP GrabCAD), up nguoc tren tang 1
Tru dong M3x20 do dong co 1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

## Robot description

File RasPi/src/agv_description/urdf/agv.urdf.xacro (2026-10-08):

<?xml version="1.0"?>
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
<robot xmlns:xacro="http://www.ros.org/wiki/xacro" name="agv">

  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
  <xacro:property name="plate_size" value="0.30"/>   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
  <xacro:property name="plate_thickness" value="0.005"/>  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
  <xacro:property name="plate_gap" value="0.10"/>   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
  <xacro:property name="plate1_below_axle" value="0.0125"/> 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
  <xacro:property name="standoff_radius" value="0.003"/>  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
  <xacro:property name="standoff_inset" value="0.015"/>  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
  <xacro:property name="payload_size_x" value="0.20"/>   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
  <xacro:property name="payload_size_y" value="0.16"/>   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
  <xacro:property name="payload_size_z" value="0.05"/>   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
  <xacro:property name="body_mass" value="2.2"/>    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
  <xacro:property name="wheel_radius" value="0.0325"/> 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
  <xacro:property name="wheel_width" value="0.027"/>  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
  <xacro:property name="wheel_mass" value="0.08"/>   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
  <xacro:property name="wheelbase" value="0.20"/>   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
  <xacro:property name="track_width" value="0.34"/>   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
  <xacro:property name="effective_track" value="0.45"/>   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
  <xacro:property name="lidar_x" value="0.0"/>    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
  <xacro:property name="lidar_radius" value="0.035"/>  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
  <xacro:property name="lidar_height" value="0.035"/>  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
  <xacro:property name="lift_plate_size" value="0.26"/>
  <xacro:property name="lift_plate_thickness" value="0.01"/>
  <xacro:property name="lift_gap" value="0.002"/>  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
  <xacro:property name="lift_stroke" value="0.03"/>   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
  <xacro:property name="lift_speed" value="0.02"/>   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
  <xacro:property name="plate1_z" value="${plate1_below_axle + plate_thickness / 2}"/>
  <xacro:property name="plate1_top" value="${plate1_below_axle + plate_thickness}"/>
  <xacro:property name="plate2_z" value="${plate1_top + plate_gap + plate_thickness / 2}"/>
  <xacro:property name="plate2_top" value="${plate1_top + plate_gap + plate_thickness}"/>
  <xacro:property name="standoff_xy" value="${plate_size / 2 - standoff_inset}"/>

  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
  <xacro:macro name="box_inertia" params="m x y z *origin">
    <inertial>
      <xacro:insert_block name="origin"/>
      <mass value="${m}"/>
      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
    </inertial>
  </xacro:macro>

  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
  <xacro:macro name="cylinder_inertia" params="m r h *origin">
    <inertial>
      <xacro:insert_block name="origin"/>
      <mass value="${m}"/>
      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
    </inertial>
  </xacro:macro>

  <xacro:macro name="standoff" params="x y">
    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
  </xacro:macro>

  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
  <link name="base_footprint"/>

  <joint name="base_joint" type="fixed">
    <parent link="base_footprint"/>
    <child link="base_link"/>
    <origin xyz="0 0 ${wheel_radius}" rpy="0 0 0"/>
  </joint>

  <link name="base_link">
    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
    <xacro:standoff x="${ standoff_xy}" y="${ standoff_xy}"/>
    <xacro:standoff x="${ standoff_xy}" y="${-standoff_xy}"/>
    <xacro:standoff x="${-standoff_xy}" y="${ standoff_xy}"/>
    <xacro:standoff x="${-standoff_xy}" y="${-standoff_xy}"/>

    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
    <xacro:box_inertia m="${body_mass}" x="${plate_size}" y="${plate_size}" z="${payload_size_z}">
      <origin xyz="0 0 ${plate1_top + payload_size_z / 2}"/>
    </xacro:box_inertia>
  </link>

  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
  <xacro:macro name="wheel" params="prefix x y">
    <link name="wheel_${prefix}_link">
      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
      <xacro:cylinder_inertia m="${wheel_mass}" r="${wheel_radius}" h="${wheel_width}">
        <origin xyz="0 0 0" rpy="${pi/2} 0 0"/>
      </xacro:cylinder_inertia>
    </link>

    <joint name="wheel_${prefix}_joint" type="continuous">
      <parent link="base_link"/>
      <child link="wheel_${prefix}_link"/>
      <origin xyz="${x} ${y} 0" rpy="0 0 0"/>
      <axis xyz="0 1 0"/>
    </joint>
  </xacro:macro>

  <xacro:wheel prefix="fl" x="${ wheelbase/2}" y="${ track_width/2}"/>
  <xacro:wheel prefix="fr" x="${ wheelbase/2}" y="${-track_width/2}"/>
  <xacro:wheel prefix="rl" x="${-wheelbase/2}" y="${ track_width/2}"/>
  <xacro:wheel prefix="rr" x="${-wheelbase/2}" y="${-track_width/2}"/>

  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
  <link name="laser_frame">
    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
    <xacro:cylinder_inertia m="0.1" r="${lidar_radius}" h="${lidar_height}">
      <origin xyz="0 0 0" rpy="0 0 0"/>
    </xacro:cylinder_inertia>
  </link>

  <joint name="laser_joint" type="fixed">
    <parent link="base_link"/>
    <child link="laser_frame"/>
    <origin xyz="${lidar_x} 0 ${plate1_top + payload_size_z + lidar_height / 2}" rpy="0 0 0"/>
  </joint>

  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
  <link name="lift_plate">
    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
    <xacro:box_inertia m="0.15" x="${lift_plate_size}" y="${lift_plate_size}" z="${lift_plate_thickness}">
      <origin xyz="0 0 0"/>
    </xacro:box_inertia>
  </link>

  <joint name="lift_joint" type="prismatic">
    <parent link="base_link"/>
    <child link="lift_plate"/>
    <origin xyz="0 0 ${plate2_top + lift_gap + lift_plate_thickness / 2}" rpy="0 0 0"/>
    <axis xyz="0 0 1"/>
    <limit lower="0.0" upper="${lift_stroke}" effort="300" velocity="${lift_speed}"/>
  </joint>

  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
  <link name="imu_link">
    <xacro:box_inertia m="0.01" x="0.02" y="0.02" z="0.005">
      <origin xyz="0 0 0"/>
    </xacro:box_inertia>
  </link>

  <joint name="imu_joint" type="fixed">
    <parent link="base_link"/>
    <child link="imu_link"/>
    <origin xyz="0 0 ${plate1_top}" rpy="0 0 0"/>
  </joint>

  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
  <xacro:include filename="agv_gazebo.xacro"/>

</robot>

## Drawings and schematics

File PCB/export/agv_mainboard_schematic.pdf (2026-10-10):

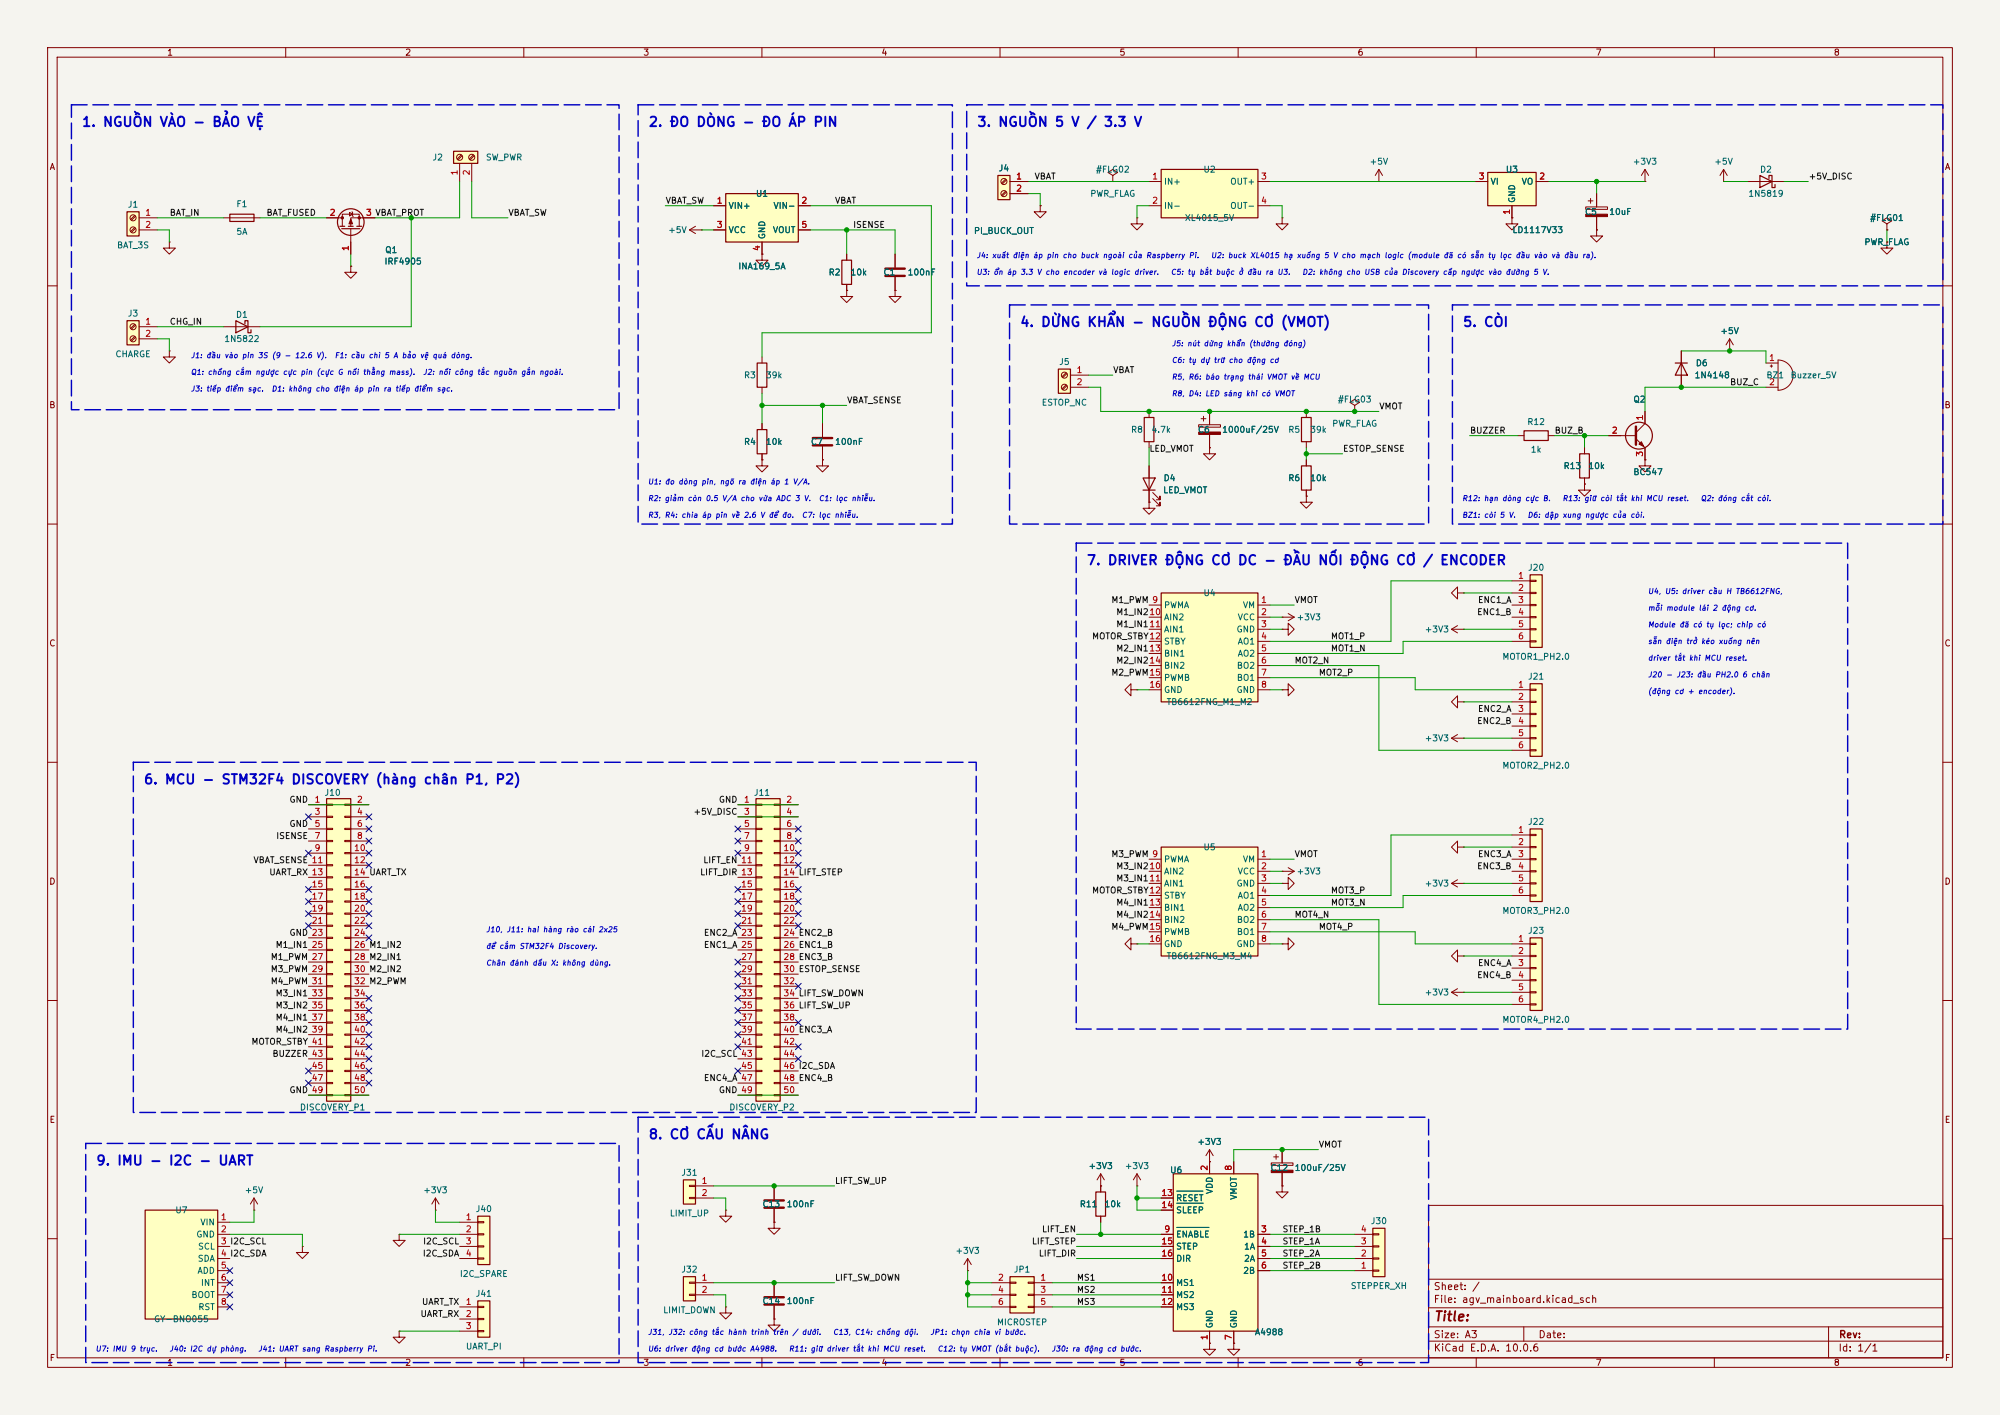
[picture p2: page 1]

2. ĐO DÒNG - ĐO ÁP PIN

sẵn điện trở kéo xuống nên Module đã có tụ lọc; chip có U4, U5: driver cầu H TB6612FNG, 7. DRIVER ĐỘNG CƠ DC - ĐẦU NỐI ĐỘNG CƠ / ENCODER
TB6612FNG_M1_M2 GND

6. MCU - STM32F4 DISCOVERY (hàng chân P1, P2)

J10, J11: hai hàng rào cái 2x25

Chân đánh dấu X: không dùng.

Size: A3 | Rev: | F Date:
KiCad E.D.A. 10.0.6 | Id: 1/1

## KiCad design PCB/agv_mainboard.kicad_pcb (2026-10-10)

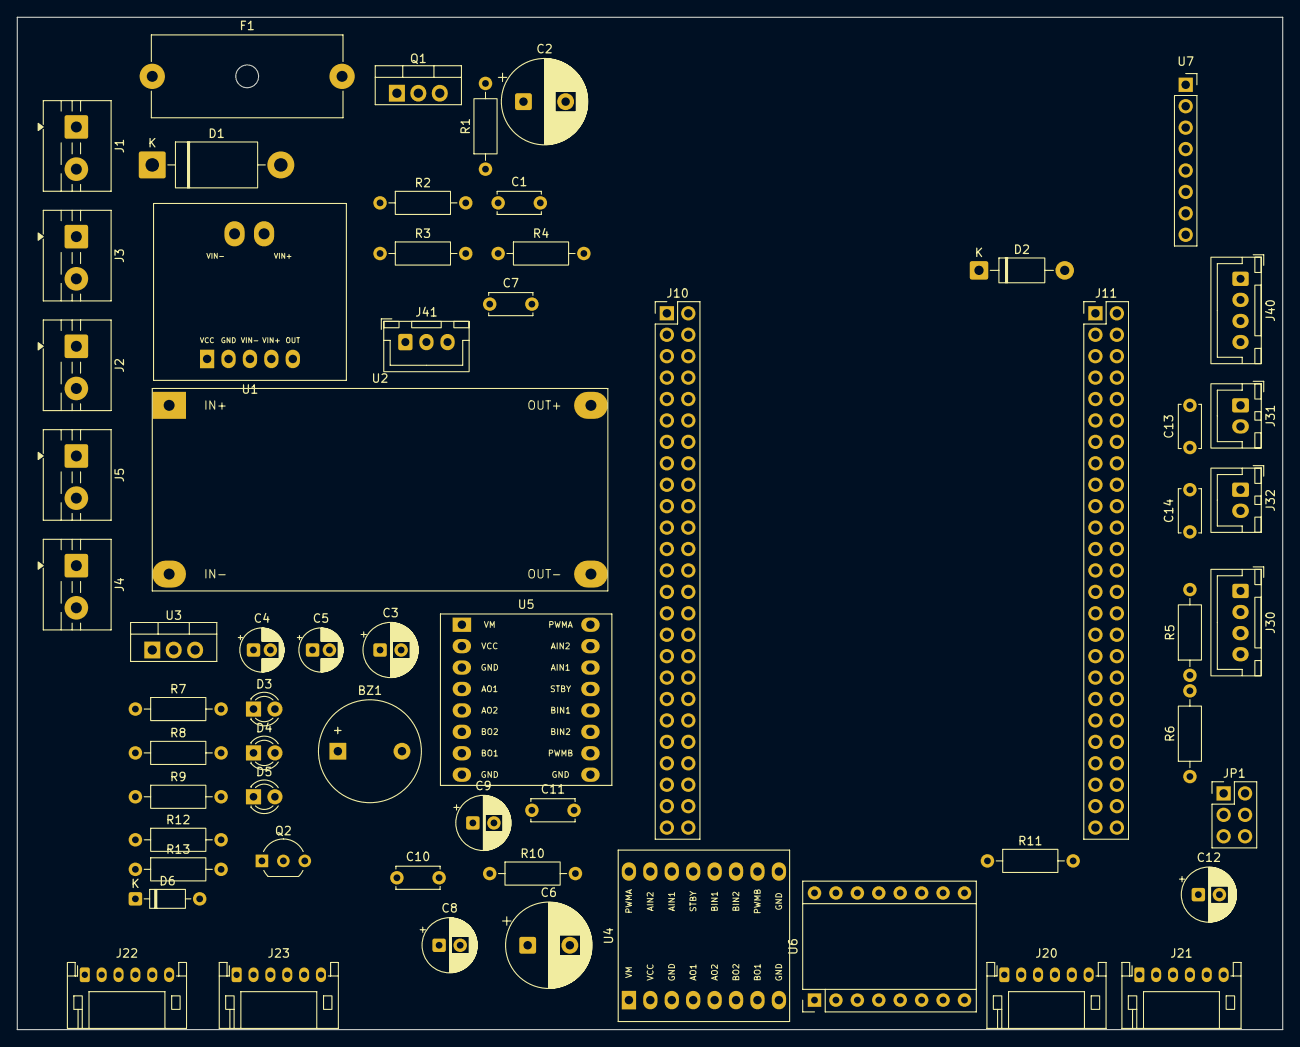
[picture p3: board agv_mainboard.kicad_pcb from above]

Board: 2 copper layers, 150.0 x 120.0 mm, 61 parts (0 on the bottom side), 66 nets, no tracks yet.

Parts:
BZ1: Buzzer_5V; Buzzer_12x9.5RM7.6
C1, C7, C10, C11, C13, C14: 100nF; C_Disc_D5.0mm_W2.5mm_P5.00mm
C2, C6: 1000uF/25V; CP_Radial_D10.0mm_P5.00mm
C3, C8, C9, C12: 100uF/25V; CP_Radial_D6.3mm_P2.50mm
C4, C5: 10uF; CP_Radial_D5.0mm_P2.00mm
D1: 1N5822; D_DO-201AD_P15.24mm_Horizontal
D2: 1N5819; D_DO-41_SOD81_P10.16mm_Horizontal
D3: LED_VBAT; LED_D3.0mm
D4: LED_VMOT; LED_D3.0mm
D5: LED_5V; LED_D3.0mm
D6: 1N4148; D_DO-35_SOD27_P7.62mm_Horizontal
F1: 5A; Fuseholder_Cylinder-5x20mm_Schurter_0031_8201_Horizontal_Op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
J1: BAT_3S; TerminalBlock_MaiXu_MX126-5.0-02P_1x02_P5.00mm
J2: SW_PWR; TerminalBlock_MaiXu_MX126-5.0-02P_1x02_P5.00mm
J3: CHARGE; TerminalBlock_MaiXu_MX126-5.0-02P_1x02_P5.00mm
J4: PI_BUCK_OUT; TerminalBlock_MaiXu_MX126-5.0-02P_1x02_P5.00mm
J5: ESTOP_NC; TerminalBlock_MaiXu_MX126-5.0-02P_1x02_P5.00mm
J10: DISCOVERY_P1; PinHeader_2x25_P2.54mm_Vertical
J11: DISCOVERY_P2; PinHeader_2x25_P2.54mm_Vertical
J20: MOTOR1_PH2.0; JST_PH_S6B-PH-K_1x06_P2.00mm_Horizontal
J21: MOTOR2_PH2.0; JST_PH_S6B-PH-K_1x06_P2.00mm_Horizontal
J22: MOTOR3_PH2.0; JST_PH_S6B-PH-K_1x06_P2.00mm_Horizontal
J23: MOTOR4_PH2.0; JST_PH_S6B-PH-K_1x06_P2.00mm_Horizontal
J30: STEPPER_XH; JST_XH_B4B-XH-A_1x04_P2.50mm_Vertical
J31: LIMIT_UP; JST_XH_B2B-XH-A_1x02_P2.50mm_Vertical
J32: LIMIT_DOWN; JST_XH_B2B-XH-A_1x02_P2.50mm_Vertical
J40: I2C_SPARE; JST_XH_B4B-XH-A_1x04_P2.50mm_Vertical
J41: UART_PI; JST_XH_B3B-XH-A_1x03_P2.50mm_Vertical
JP1: MICROSTEP; PinHeader_2x03_P2.54mm_Vertical
Q1: IRF4905; TO-220-3_Vertical
Q2: BC547; TO-92_Inline_Wide
R1: 100k; R_Axial_DIN0207_L6.3mm_D2.5mm_P10.16mm_Horizontal
R2, R4, R6, R10, R11, R13: 10k; R_Axial_DIN0207_L6.3mm_D2.5mm_P10.16mm_Horizontal
R3, R5: 39k; R_Axial_DIN0207_L6.3mm_D2.5mm_P10.16mm_Horizontal
R7, R8: 4.7k; R_Axial_DIN0207_L6.3mm_D2.5mm_P10.16mm_Horizontal
R9, R12: 1k; R_Axial_DIN0207_L6.3mm_D2.5mm_P10.16mm_Horizontal
U1: INA169_5A; INA169_Module
U2: XL4015_5V; XL4015_Module
U3: LD1117V33; TO-220-3_Vertical
U4: TB6612FNG_M1_M2; TB6612FNG_Module
U5: TB6612FNG_M3_M4; TB6612FNG_Module
U6: A4988; Pololu_Breakout-16_15.2x20.3mm
U7: GY-BNO055; PinSocket_1x08_P2.54mm_Vertical

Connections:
+3V3: C5.1, C10.1, C11.1, J20.5, J21.5, J22.5, J23.5, J40.1, JP1.2, JP1.4, JP1.6, R11.1, U3.2, U4.2, U5.2, U6.2, U6.13, U6.14
+5V: BZ1.1, C3.1, C4.1, D2.2, D6.1, R9.1, U1.3, U2.3, U3.3, U7.1
+5V_DISC: D2.1, J11.3, J11.4
BAT_FUSED: F1.2, Q1.2
BAT_IN: F1.1, J1.1
BUZZER: J10.43, R12.1
BUZ_B: Q2.2, R12.2, R13.1
BUZ_C: BZ1.2, D6.2, Q2.1
CHG_IN: D1.2, J3.1
ENC1_A: J11.25, J20.3
ENC1_B: J11.26, J20.4
ENC2_A: J11.23, J21.3
ENC2_B: J11.24, J21.4
ENC3_A: J11.40, J22.3
ENC3_B: J11.28, J22.4
ENC4_A: J11.47, J23.3
ENC4_B: J11.48, J23.4
ESTOP_SENSE: J11.30, R5.2, R6.1
GND: C1.2, C2.2, C3.2, C4.2, C5.2, C6.2, C7.2, C8.2, C9.2, C10.2, C11.2, C12.2, C13.2, C14.2, D3.1, D4.1, D5.1, J1.2, J3.2, J4.2, J10.1, J10.2, J10.5, J10.23, J10.49, J10.50, J11.1, J11.2, J11.49, J11.50, J20.2, J21.2, J22.2, J23.2, J31.2, J32.2, J40.2, J41.3, Q2.3, R1.2, R2.2, R4.2, R6.2, R10.2, R13.2, U1.4, U2.2, U2.4, U3.1, U4.3, U4.8, U4.16, U5.3, U5.8, U5.16, U6.1, U6.7, U7.2
I2C_SCL: J11.43, J40.3, U7.3
I2C_SDA: J11.46, J40.4, U7.4
ISENSE: C1.1, J10.7, R2.1, U1.5
LED_5V: D5.2, R9.2
LED_VBAT: D3.2, R7.2
LED_VMOT: D4.2, R8.2
LIFT_DIR: J11.13, U6.16
LIFT_EN: J11.11, R11.2, U6.9
LIFT_STEP: J11.14, U6.15
LIFT_SW_DOWN: C14.1, J11.34, J32.1
LIFT_SW_UP: C13.1, J11.36, J31.1
M1_IN1: J10.25, U4.11
M1_IN2: J10.26, U4.10
M1_PWM: J10.27, U4.9
M2_IN1: J10.28, U4.13
M2_IN2: J10.30, U4.14
M2_PWM: J10.32, U4.15
M3_IN1: J10.33, U5.11
M3_IN2: J10.35, U5.10
M3_PWM: J10.29, U5.9
M4_IN1: J10.37, U5.13
M4_IN2: J10.39, U5.14
M4_PWM: J10.31, U5.15
MOT1_N: J20.6, U4.5
MOT1_P: J20.1, U4.4
MOT2_N: J21.6, U4.6
MOT2_P: J21.1, U4.7
MOT3_N: J22.6, U5.5
MOT3_P: J22.1, U5.4
MOT4_N: J23.6, U5.6
MOT4_P: J23.1, U5.7
MOTOR_STBY: J10.41, R10.1, U4.12, U5.12
MS1: JP1.1, U6.10
MS2: JP1.3, U6.11
MS3: JP1.5, U6.12
Q1_G: Q1.1, R1.1
STEP_1A: J30.3, U6.4
STEP_1B: J30.4, U6.3
STEP_2A: J30.2, U6.5
STEP_2B: J30.1, U6.6
UART_RX: J10.13, J41.2
UART_TX: J10.14, J41.1
VBAT: C2.1, J4.1, J5.1, R3.1, R7.1, U1.2, U2.1
VBAT_PROT: D1.1, J2.1, Q1.3
VBAT_SENSE: C7.1, J10.11, R3.2, R4.1
VBAT_SW: J2.2, U1.1
VMOT: C6.1, C8.1, C9.1, C12.1, J5.2, R5.1, R8.1, U4.1, U5.1, U6.8

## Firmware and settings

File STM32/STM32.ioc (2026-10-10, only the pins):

Mcu.UserName=STM32F407VGTx
PA1.Signal=ADCx_IN1
PA13.Signal=SYS_JTMS-SWDIO
PA14.Signal=SYS_JTCK-SWCLK
PA15.Signal=S_TIM2_CH1_ETR
PA2.Signal=USART2_TX
PA3.Signal=USART2_RX
PA8.Signal=I2C3_SCL
PB11.GPIO_Label=M3_IN2
PB11.Signal=GPIO_Output
PB13.GPIO_Label=M4_IN1
PB13.Signal=GPIO_Output
PB15.GPIO_Label=M4_IN2
PB15.Signal=GPIO_Output
PB3.Signal=S_TIM2_CH2
PB4.Signal=S_TIM3_CH1
PB5.Signal=S_TIM3_CH2
PB6.Signal=S_TIM4_CH1
PB7.Signal=S_TIM4_CH2
PC1.Signal=ADCx_IN11
PC6.Signal=S_TIM8_CH1
PC7.Signal=S_TIM8_CH2
PC9.Signal=I2C3_SDA
PD0.GPIO_Label=LIFT_SW_UP
PD0.Signal=GPIO_Input
PD11.GPIO_Label=BUZZER
PD11.Signal=GPIO_Output
PD2.GPIO_Label=LIFT_SW_DOWN
PD2.Signal=GPIO_Input
PD4.GPIO_Label=AUDIO_RST
PD4.Signal=GPIO_Output
PD6.GPIO_Label=ESTOP_SENSE
PD6.Signal=GPIO_Input
PD9.GPIO_Label=MOTOR_STBY
PD9.Signal=GPIO_Output
PE10.GPIO_Label=M2_IN1
PE10.Signal=GPIO_Output
PE11.Signal=S_TIM1_CH2
PE12.GPIO_Label=M2_IN2
PE12.Signal=GPIO_Output
PE13.Signal=S_TIM1_CH3
PE14.Signal=S_TIM1_CH4
PE15.GPIO_Label=M3_IN1
PE15.Signal=GPIO_Output
PE4.GPIO_Label=LIFT_DIR
PE4.Signal=GPIO_Output
PE5.Signal=S_TIM9_CH1
PE6.GPIO_Label=LIFT_EN
PE6.Signal=GPIO_Output
PE7.GPIO_Label=M1_IN1
PE7.Signal=GPIO_Output
PE8.GPIO_Label=M1_IN2
PE8.Signal=GPIO_Output
PE9.Signal=S_TIM1_CH1
PH0-OSC_IN.Signal=RCC_OSC_IN
PH1-OSC_OUT.Signal=RCC_OSC_OUT

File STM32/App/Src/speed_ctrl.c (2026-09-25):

/**
  * @file    speed_ctrl.c
  * @brief   Dieu khien toc do vong kin cho dong co GA25-370 qua L298N
  *
  * Cau truc: duty = feedforward(toc_do_dat) + PID(sai_lech)
  *
  * Feedforward lay tu bang do thuc te tren dong co that (PWM 1 kHz, khong tai,
  * nguon 12V). Nho no ma PID chi phai bu phan sai lech nho, thay vi tu do tim
  * tu 0 moi lan doi lenh - dap ung nhanh hon va it vot lo hon han.
  *
  * Bang do duoc (xem docs, duty %  ->  RPM truc ra):
  *   30 -> 96.5   35 -> 128.3   40 -> 153.6   45 -> 174.9
  *   50 -> 191.6  60 -> 210.3   100 -> 278.6
  * Duoi 30 % dong co khong quay (vung chet do ma sat tinh).
  */
#include "speed_ctrl.h"
#include "motor.h"
#include "encoder.h"
#include "pid.h"

/*
 * He so PID. Don vi: % duty tren moi RPM sai lech.
 *
 * Do tu dong bang bai thu 0 -> 120 -> 240 -> 120 RPM, khong tai, PWM 1 kHz:
 *
 *   Kp/Ki/Kd          vot lo 0->120   hut 240->120   on dinh TB   sai so TB
 *   0.12/0.50/0.01        11.3%           5.4%         2.60s        1.6
 *   0.20/0.50/0.01         9.1%           3.2%         2.35s        1.3
 *   0.20/0.90/0.01        14.7%          15.4%         1.63s        0.1   <- dang dung
 *   0.20/0.90/0.03        18.0%          15.4%         1.57s        0.2
 *   0.30/0.90/0.01        10.2%          10.9%         2.02s        0.4
 *
 * Chon 0.20/0.90/0.01: sai so xac lap gan nhu bang 0 va on dinh nhanh nhat.
 * Doi lai vot lo 15% trong khoang nua giay, chap nhan duoc voi AGV.
 * Muon chay em hon thi dung 0.20/0.50/0.01, vot lo con 9% nhung cham hon 0.7s.
 *
 * Kd gan nhu khong tac dung vi feedforward da lo phan lon; tang len 0.03 chi
 * lam vot lo xau di.
 */
#define SPD_KP   0.20f
#define SPD_KI   0.90f   /* % duty / (RPM * giay) */
#define SPD_KD   0.01f   /* % duty * giay / RPM   */

/* Bang feedforward, RPM tang dan */
static const float ff_rpm[]  = {  96.5f, 128.3f, 153.6f, 174.9f, 191.6f, 210.3f, 278.6f };
static const float ff_duty[] = {  30.0f,  35.0f,  40.0f,  45.0f,  50.0f,  60.0f, 100.0f };
#define FF_POINTS  (sizeof(ff_rpm) / sizeof(ff_rpm[0]))

static PID_t   pid;
static int16_t target_rpm = 0;
static int16_t out_duty   = 0;

/* Noi suy tuyen tinh tung doan; ngoai bang thi giu gia tri dau/cuoi */
static float feedforward(float rpm)
{
  if (rpm <= ff_rpm[0])              return ff_duty[0];
  if (rpm >= ff_rpm[FF_POINTS - 1])  return ff_duty[FF_POINTS - 1];

  for (unsigned i = 1; i < FF_POINTS; i++)
  {
    if (rpm <= ff_rpm[i])
    {
      float t = (rpm - ff_rpm[i - 1]) / (ff_rpm[i] - ff_rpm[i - 1]);
      return ff_duty[i - 1] + t * (ff_duty[i] - ff_duty[i - 1]);
    }
  }
  return ff_duty[FF_POINTS - 1];
}

void SpeedCtrl_Init(void)
{
  /* PID chi bu sai lech con lai nen gioi han hep hon toan dai duty */
  PID_Init(&pid, SPD_KP, SPD_KI, SPD_KD, -40.0f, 40.0f);
  target_rpm = 0;
  out_duty   = 0;
}

void SpeedCtrl_SetTarget(int16_t rpm)
{
  if (rpm > 0)
  {
    if (rpm < SPD_RPM_MIN) rpm = SPD_RPM_MIN;
    if (rpm > SPD_RPM_MAX) rpm = SPD_RPM_MAX;
  }
  else if (rpm < 0)
  {
    if (rpm > -SPD_RPM_MIN) rpm = -SPD_RPM_MIN;
    if (rpm < -SPD_RPM_MAX) rpm = -SPD_RPM_MAX;
  }

  /* Doi chieu hoac dung han: xoa trang thai cu de khong mang tich phan sang */
  if ((rpm == 0) || ((target_rpm < 0) != (rpm < 0)))
    PID_Reset(&pid);

  target_rpm = rpm;
}

void SpeedCtrl_Update(uint32_t dt_ms)
{
  if (target_rpm == 0)
  {
    Motor_Coast();
    out_duty = 0;
    PID_Reset(&pid);
    return;
  }

  float dt      = (float)dt_ms / 1000.0f;
  float meas    = (float)Encoder_GetRpmX10() / 10.0f;
  float sp      = (float)target_rpm;

  /* Tinh toan theo tri tuyet doi roi gan lai dau, de bang feedforward
     dung chung cho ca hai chieu quay */
  float sign    = (sp < 0.0f) ? -1.0f : 1.0f;
  float sp_abs  = sp * sign;
  float meas_abs = meas * sign;

  float ff  = feedforward(sp_abs);
  float fb  = PID_Update(&pid, sp_abs, meas_abs, dt);
  float duty = ff + fb;

  if (duty > 100.0f) duty = 100.0f;
  if (duty < 0.0f)   duty = 0.0f;

  out_duty = (int16_t)(duty * sign);
  Motor_SetSpeed(out_duty);
}

void SpeedCtrl_SetGains(float kp, float ki, float kd)
{
  PID_SetTunings(&pid, kp, ki, kd);
}

void SpeedCtrl_GetGains(float *kp, float *ki, float *kd)
{
  if (kp) *kp = pid.kp;
  if (ki) *ki = pid.ki;
  if (kd) *kd = pid.kd;
}

int16_t SpeedCtrl_GetTarget(void) { return target_rpm; }
int16_t SpeedCtrl_GetDuty(void)   { return out_duty; }

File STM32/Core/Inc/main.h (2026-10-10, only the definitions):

#define LIFT_DIR_Pin GPIO_PIN_4
#define LIFT_DIR_GPIO_Port GPIOE
#define LIFT_EN_Pin GPIO_PIN_6
#define LIFT_EN_GPIO_Port GPIOE
#define M1_IN1_Pin GPIO_PIN_7
#define M1_IN1_GPIO_Port GPIOE
#define M1_IN2_Pin GPIO_PIN_8
#define M1_IN2_GPIO_Port GPIOE
#define M2_IN1_Pin GPIO_PIN_10
#define M2_IN1_GPIO_Port GPIOE
#define M2_IN2_Pin GPIO_PIN_12
#define M2_IN2_GPIO_Port GPIOE
#define M3_IN1_Pin GPIO_PIN_15
#define M3_IN1_GPIO_Port GPIOE
#define M3_IN2_Pin GPIO_PIN_11
#define M3_IN2_GPIO_Port GPIOB
#define M4_IN1_Pin GPIO_PIN_13
#define M4_IN1_GPIO_Port GPIOB
#define M4_IN2_Pin GPIO_PIN_15
#define M4_IN2_GPIO_Port GPIOB
#define MOTOR_STBY_Pin GPIO_PIN_9
#define MOTOR_STBY_GPIO_Port GPIOD
#define BUZZER_Pin GPIO_PIN_11
#define BUZZER_GPIO_Port GPIOD
#define LIFT_SW_UP_Pin GPIO_PIN_0
#define LIFT_SW_UP_GPIO_Port GPIOD
#define LIFT_SW_DOWN_Pin GPIO_PIN_2
#define LIFT_SW_DOWN_GPIO_Port GPIOD
#define AUDIO_RST_Pin GPIO_PIN_4
#define AUDIO_RST_GPIO_Port GPIOD
#define ESTOP_SENSE_Pin GPIO_PIN_6
#define ESTOP_SENSE_GPIO_Port GPIOD

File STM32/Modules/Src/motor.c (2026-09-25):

/**
  * @file    motor.c
  * @brief   Driver L298N cho 1 dong co DC
  */
#include "motor.h"
#include "tim.h"
#include "gpio.h"

/* Doi chan / them motor thu 2 chi can sua o day */
#define MOTOR_PWM_TIM      htim1
#define MOTOR_PWM_CH       TIM_CHANNEL_1
#define MOTOR_IN1_PORT     GPIOE
#define MOTOR_IN1_PIN      GPIO_PIN_7
#define MOTOR_IN2_PORT     GPIOE
#define MOTOR_IN2_PIN      GPIO_PIN_8

static int16_t motor_duty = 0;

static void motor_set_dir(GPIO_PinState in1, GPIO_PinState in2)
{
  HAL_GPIO_WritePin(MOTOR_IN1_PORT, MOTOR_IN1_PIN, in1);
  HAL_GPIO_WritePin(MOTOR_IN2_PORT, MOTOR_IN2_PIN, in2);
}

static void motor_set_pwm(uint16_t duty)
{
  __HAL_TIM_SET_COMPARE(&MOTOR_PWM_TIM, MOTOR_PWM_CH, duty);
}

void Motor_Init(void)
{
  motor_set_dir(GPIO_PIN_RESET, GPIO_PIN_RESET);
  motor_set_pwm(0);
  /* TIM1 la advanced timer: HAL_TIM_PWM_Start tu bat MOE */
  HAL_TIM_PWM_Start(&MOTOR_PWM_TIM, MOTOR_PWM_CH);
  motor_duty = 0;
}

void Motor_SetSpeed(int16_t duty)
{
  if (duty > MOTOR_DUTY_MAX)  duty = MOTOR_DUTY_MAX;
  if (duty < -MOTOR_DUTY_MAX) duty = -MOTOR_DUTY_MAX;

  if (duty > 0)
  {
    motor_set_dir(GPIO_PIN_SET, GPIO_PIN_RESET);
    motor_set_pwm((uint16_t)duty);
  }
  else if (duty < 0)
  {
    motor_set_dir(GPIO_PIN_RESET, GPIO_PIN_SET);
    motor_set_pwm((uint16_t)(-duty));
  }
  else
  {
    motor_set_pwm(0);
    motor_set_dir(GPIO_PIN_RESET, GPIO_PIN_RESET);
  }
  motor_duty = duty;
}

void Motor_Brake(void)
{
  motor_set_dir(GPIO_PIN_SET, GPIO_PIN_SET);
  motor_set_pwm(MOTOR_DUTY_MAX);
  motor_duty = 0;
}

void Motor_Coast(void)
{
  motor_set_pwm(0);
  motor_set_dir(GPIO_PIN_RESET, GPIO_PIN_RESET);
  motor_duty = 0;
}

int16_t Motor_GetSpeed(void)
{
  return motor_duty;
}

uint32_t Motor_GetPwmFreqHz(void)
{
  /* TIM1 nam tren APB2: khi APB2 prescaler != 1 thi timer clock = PCLK2 * 2 */
  uint32_t pclk2   = HAL_RCC_GetPCLK2Freq();
  uint32_t tim_clk = ((RCC->CFGR & RCC_CFGR_PPRE2) == 0U) ? pclk2 : pclk2 * 2U;
  uint32_t psc     = MOTOR_PWM_TIM.Instance->PSC + 1U;
  uint32_t arr     = MOTOR_PWM_TIM.Instance->ARR + 1U;

  return tim_clk / (psc * arr);
}

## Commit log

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2026-09-25 build(stm32): add FreeRTOS middleware and HAL drivers for TIM, UART and DMA
2026-09-25 build(stm32): regenerate CubeMX project with TIM1, TIM3, USART2 and FreeRTOS
    TIM1 CH1 phat PWM 1 kHz tren PE9, TIM3 doc encoder che do TI12 tren PB4/PB5,
    USART2 115200 tren PA2/PA3 kem DMA1 Stream 6 cho chieu truyen.
    Chan PE7/PE8 lam ngo ra dieu khien chieu quay cua L298N.
2026-09-25 feat(stm32): add motor driver for L298N and encoder reader
    Hang so encoder do truc tiep tren dong co that: 898 xung moi vong truc ra,
    tuc ti so hop so 20.4:1 chu khong phai 21.3:1 nhu nhan hang ghi.
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2026-09-25 feat(stm32): add discrete PID with anti-windup
    Dao ham tinh tren gia tri do de doi setpoint khong gay xung dao ham.
    Chong bao hoa tich phan bang back-calculation.
2026-09-25 feat(stm32): add closed-loop speed control with measured feedforward
    Feedforward noi suy tu bang duty-RPM do duoc tren dong co that, nen PID chi
    phai bu phan sai lech nho. He so Kp 0.20 / Ki 0.90 / Kd 0.01 chon tu bang
    so lieu 5 bo tham so ghi trong comment dau file.
2026-09-25 feat(stm32): add UART CLI for duty, speed and PID gains
    Chinh he so va toc do dat luc dang chay, khong phai bien dich va nap lai.
2026-09-25 feat(stm32): wire app layer into main and CMake build
    main.c chi goi App_Init, con lai nam trong App/ va Modules/ de CubeMX khong
    ghi de khi generate lai.
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2026-09-25 feat(tools): add log plotting and live PID tuning scripts
    plot_speed.py ve dap ung tu file log va tinh vot lo, thoi gian on dinh,
    sai so xac lap. tune.py vua ve do thi truc tiep vua gui lenh xuong board.
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2026-09-25 docs(skills): require Modules/App layout for hand-written code
    Code tu viet khong dat trong Core/ nua: driver vao Modules/, logic vao App/,
    main.c chi goi App_Init. check_ioc.py canh bao khi co file lac cho hoac chua
    dang ky voi CMake.
2026-10-07 feat(raspi): add AGV URDF description with lidar and IMU
    [agv.urdf.xacro, agv_gazebo.xacro]
2026-10-07 feat(raspi): add Gazebo Harmonic warehouse simulation
    [warehouse.sdf]
2026-10-07 feat(raspi): add motor model that mimics firmware RPM limits
    Gazebo DiffDrive tracks any requested wheel speed, while the real
    firmware forces nonzero targets into 100-270 RPM. Route /cmd_vel through
    a node that applies the same limits so Nav2 tuning sees real behavior.
    [agv_gazebo.xacro]
2026-10-07 feat(raspi): add ground truth and odom drift measurement tool
    [agv_gazebo.xacro]
2026-10-07 docs(raspi): document motor model limits and odom drift results
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2026-10-07 feat(raspi): add gyro bias to simulated IMU
    Without bias the integrated yaw never drifts, making the EKF look better
    in simulation than it will be with the real BNO055.
    [agv_gazebo.xacro]
2026-10-07 feat(raspi): route simulated wheel odometry through EKF
    DiffDrive odom carries zero covariance, so add it in a sim-only node and
    publish /wheel/odom like the future STM32 bridge. EKF now owns /odom and
    the odom -> base_footprint transform.
    [agv_gazebo.xacro]
2026-10-07 fix(raspi): declare single vertical ray for simulated lidar
    [agv_gazebo.xacro]
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2026-10-07 fix(raspi): run Gazebo GUI separately so its crash keeps sim alive
    The WSL GPU driver sometimes segfaults while the Gazebo GUI initializes
    OpenGL. With server and GUI in one required process, that shut down the
    whole launch. Split them as linorobot2 does and only require the server.
2026-10-07 feat(raspi): preserve turning radius when motor deadband applies
    When a wheel target falls below the firmware minimum, scale both wheels
    up together instead of letting the firmware bump each wheel to 100 RPM.
    Without this, slow corrective steering became straight driving and Nav2
    drifted into shelves in 1 m aisles. Mirrors preserve_turning_radius of
    Clearpath's diff_drive_controller; the Pi-STM32 bridge must do the same.
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2026-10-07 feat(raspi): add Nav2 navigation with keepout filter
    Start from Nav2 Jazzy default params and swap in linorobot2's
    RotationShim + Regulated Pure Pursuit controller. Keepout servers follow
    nav2_costmap_filters_demo as separate processes; loading them into
    nav2_container left the robot unable to move.
2026-10-07 fix(raspi): load keepout servers into nav2_container
    With separate processes the keepout lifecycle manager hung at
    "Configuring filter_mask_server" under GUI load, so the mask never
    appeared. The earlier "robot never moves" result with composition came
    from a flawed test script that flooded AMCL with initial poses; with the
    fixed script composition passes 4/4 goals.
2026-10-07 docs: add progress report with mistakes and fixes
    Record what was built, which tools were used, and every notable mistake
    with how it was found and fixed, as source material for the course
    report.
2026-10-07 feat(raspi): add warehouse mission package
    Named stations, predefined missions and a mission server that drives
    Nav2 through NavigateToPose with one retry per leg. agv_cmd.py sends
    goto/run/cancel commands from a terminal. The server waits for
    bt_navigator to be active before sending goals.
2026-10-07 feat(raspi): mark charging station and receiving area on warehouse floor
    [warehouse.sdf]
2026-10-07 fix(raspi): match AMCL noise model to measured odometry
    Nav2's default alpha 0.2 assumes ~45% odometry error, while the EKF odom
    drifts 2-3%. Frequent in-place turns (motor deadband) spread particles to
    1.8 m in the east zone and AMCL drifted up to 6 m. Use alpha 0.05 and
    the ROS 1 AMCL z_hit/z_rand defaults (0.95/0.05). Localization error now
    stays under 0.16 m and 12/12 goals succeed.
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2026-10-08 fix(raspi): use 3 ms physics step like Nav2 sample worlds
    Gazebo publishes /clock every physics step; at 1 ms every sim-time node
    was flooded and the sim fell behind real time (RTF 0.14-1.4), making
    odom TF lag and Nav2 abort goals. Nav2's tb3/tb4 sample worlds use 3 ms.
    [warehouse.sdf]
2026-10-08 feat(raspi): move lidar between tiers and add shelf lift plate
    The lidar on top would be covered by the shelf deck when driving under a
    shelf; between the tiers it scans at 0.12 m and also sees low pallets.
    [agv.urdf.xacro, agv_gazebo.xacro]
2026-10-08 feat(raspi): generate Kiva-style warehouse from a shelf layout file
    shelves.yaml is the single source for slot poses; make_warehouse.py writes
    the world and the docking_server dock list from it.
    [warehouse.sdf]
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2026-10-08 feat(raspi): configure Nav2 docking into shelf slots
    Rectangular footprint, shelf_dock non-charging dock type, keepout only in
    the global costmap, collision monitor height for the lower lidar.
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2026-10-08 feat(raspi): add order manager with SQLite queue for shelf transport
    Runs orders one at a time: fetch shelf, carry it to a pick station, wait
    for the operator to confirm, return it. Retries each leg once; stops and
    waits for an operator ack if a leg fails while carrying a shelf.
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2026-10-08 feat(raspi): add lidar-visible charging station behind the start pose
    The first low contact block sat in front of the start pose below the scan
    plane; the robot pushed into it while odometry kept counting.
    [warehouse.sdf]
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2026-10-08 feat(raspi): charge when idle or low before taking orders
    Waits for Nav2 to be active, keeps a per-order battery reserve, approaches
    the charger straight along its axis and backs out if undocking fails.
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2026-10-08 feat(raspi): handle faults during orders
    E-stop, blocked path (Nav2 recoveries or no progress toward the goal),
    dropped shelf and lift errors stop the robot and wait for an operator ack;
    resumable faults continue the interrupted step. Orders are requeued only
    for failures before the shelf is lifted.
2026-10-08 fix(raspi): use a rectangular footprint for carried shelves
    Detection keeps the shelf centred sideways; only the 4-6 cm overshoot
    along the robot remains, so the square footprint wasted the side gap to
    neighbouring shelves.
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2026-10-08 fix(raspi): start the sim robot docked at the charger
    The robot spawned at the map origin facing away from the charger, so the
    startup charge request kept failing and retrying, which made the robot
    circle the charger. Spawn at the charger by default (origin when SLAM),
    set the AMCL initial pose there and skip the staging approach when the
    battery already reports charging.
2026-10-08 docs: note charger start position and the circling fix
2026-10-08 feat(raspi): lock carried shelves to the lift plate in simulation
    With friction only, a lifted shelf could shift up to 10 cm on the plate
    and its legs left the scan filter box, showing up as obstacles next to
    the robot. lift_sim now attaches the shelf with a DetachableJoint once
    the plate is up and detaches it before lowering, like locating pins on
    the real lift plate. The fault test unlocks the shelf before moving it.
    [warehouse.sdf]
2026-10-08 fix(raspi): tune Nav2 for the motor deadband
    Every wheel command below 100 RPM is pushed up to it, so slow approach
    speeds, ramped stop commands and tight docking tolerances all turned
    into overshoot and circling. Never ask RPP for less than 0.35 m/s or
    1.5 rad/s, let the motors limit acceleration instead of the velocity
    smoother, and loosen the docking reset tolerances.
2026-10-08 fix(raspi): check robot pose before lifting or lowering a shelf
    The docking server only checks the distance to the slot centre, so a
    return could report success with the robot 50 degrees off and the shelf
    was lowered crooked. Verify heading and position against the slot axis
    and back out to staging and redock when they are off.
2026-10-09 feat(raspi): remove gyro bias while the wheels are still
    The EKF integrated the gyro bias while the robot stood still, so after
    ten minutes at the charger the heading was 24 degrees off and the scan
    no longer matched the map. imu_bias learns the bias whenever the wheel
    odometry reports both wheels stopped and subtracts it before the EKF.
    The simulator bridge now publishes the raw IMU on /imu/raw.
2026-10-09 fix(raspi): confirm shelf lock state before trusting it
    A single gz topic publish could be lost before it reached the plugin,
    leaving the robot welded to every shelf. Keep gz-transport publishers,
    follow each joint's state topic and resend until it matches. Also widen
    the lift tolerance to 4 mm, the plate sometimes settles at 2 mm.
2026-10-09 fix(raspi): reopen the Gazebo window after a driver crash
    The WSL NVIDIA D3D12 driver segfaults in about one launch out of four
    while the Gazebo window and RViz create their OpenGL screens together.
    Retry the window after exit code 139, up to four times.
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2026-10-09 feat(cad): add FreeCAD model of the AGV
    [agv.FCStd]
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2026-10-10 fix(skill): map I2C3 to i2c.c in check_ioc peripheral lookup
    The name was cut at the first digit (I2C3 -> I), so the check reported
    generated I2C code as missing.
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2026-10-10 feat(pcb): add mainboard schematic drawn as functional blocks
    [agv_mainboard.kicad_sch]
2026-10-10 feat(pcb): add draft component placement for the mainboard
    Work in progress: placed before the schematic was trimmed from 61 to 48
    parts, not routed, no design rules or DRC yet.
    [agv_mainboard.kicad_pcb]
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2026-10-10 feat(cad): save latest state of the FreeCAD model
    Saved in FreeCAD after the CAD pull request was merged; the changes
    inside the binary file were not reviewed in this session.
    [agv.FCStd]
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2026-10-13 fix(raspi): filter scan around base_link instead of the lidar origin
    payload_manager and shelf_detector assumed the lidar sits at the robot
    centre. With the CAD lidar 108 mm forward the body box missed the rear
    standoffs, which then showed up as obstacles inside the footprint and
    the robot stopped making progress. Both nodes now read the lidar pose
    from TF and test points in base_link.
    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
2026-10-13 feat(raspi): replace mini shelves with pallets on fixed four-post stands
    Every slot now has a static stand of four posts at the old leg positions;
    the pallet with its boxes rests on top and has no legs of its own. Empty
    slots keep their posts, which gives the lidar something to align to when
    a pallet is returned.
    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
2026-10-13 fix(raspi): use robot footprint while carrying a pallet inside its stand
    The pallet passes over the stand posts, only the robot body can hit them.
    With the pallet footprint the posts sit inside it for 0.8 m and docking
    aborts with error 905. order_manager reports payload/in_slot during lift,
    undock, return_dock and lower; payload_manager then keeps the robot
    footprint. The carried-load scan filter now defaults to the body box
    since the pallet has nothing below the scan plane.
    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
2026-10-13 fix(raspi): add support pads on stand posts so offset pallets stay on them
    Post centres are 0.72 m apart under a 0.75 m pallet, so a pallet set down
    more than 1.5 cm off centre lost one pair of posts and tipped onto the
    lift plate ("ha ke that bai: has_load True"). Each post now carries a
    12 x 12 cm pad above the lidar plane and the pallet end boards are 14 cm
    wide, which keeps the pallet supported up to about 10 cm off centre.
    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
2026-10-13 feat(raspi): return pallets by detecting the stand posts
    Empty slots keep their four posts, so return_dock can use shelf_dock and
    shelf_detector like the pickup does. Docking into the map pose made the
    trajectory graze the posts whenever AMCL was a few cm off: 17 docking
    collisions and 420 deg of wasted rotation on average per return over 8
    orders. return_detect:=false restores the map-based slot_dock.
    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
2026-10-13 fix(raspi): make shelf_detector pick the stand of the target slot
    order_manager publishes the slot it is docking into on
    shelf_detector/target; the detector keeps the square closest to that slot
    and ignores squares more than 0.35 m away. Picking the square nearest the
    robot chose a neighbouring stand whenever the robot reached staging
    30-40 deg off, and docking then grazed the posts (error 905).
    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
2026-10-13 fix(raspi): keep the corridors behind the slot rows out of navigation
    The 1.13 m corridors between the slot rows and the wall racks are too
    narrow for a robot carrying a pallet to turn (needs ~1.18 m). In
    fault_test the robot detoured into one while a wall blocked the
    warehouse and wedged there for good. No step needs these corridors, so
    make_keepout_mask.py now adds them to the keepout mask
    (shelf.back_keepout_y).
    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
2026-10-28 fix(pcb): enlarge module pin labels and tie TB6612 ground pins
    Labels go to 0.8 x 0.15 mm (JLCPCB minimum), INA219 header labels
    shortened to V-/V+, XL4015 silk outline no longer crosses its pads.
    The three GND pins of the SparkFun TB6612FNG board are joined on the
    module, so they are declared as a jumper pad group for DRC.
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2026-10-28 feat(pcb): add XT60 battery footprint, 3D model and footprint swap tool
    KiCad's XT60PW-M numbers the negative pin as 1; this copy puts pin 1
    on the positive side to match the J1 symbol (1 = BAT_IN).
2026-10-28 fix(pcb): keep existing GND zones when importing routes
    Removing zones with RemoveNative and refilling crashed KiCad 10 (exit 139).
2026-10-28 fix(pcb): face terminal blocks outward and take battery via XT60
    Wire entries of J2, J3, J5 now face the left edge and J4 the top edge.
    J1 becomes an XT60PW-M jack for a LiPo pack. Rerouted: DRC with
    schematic parity 0/0/0.
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2026-10-28 feat(cad): switch to YDLidar X2L and turn Pi USB toward the lidar
    Lidar on three 50 mm standoffs (scan plane 126.5 mm). Also refresh the
    PCB model (XT60, outward terminal blocks) and drop the broken
    Discovery STEP planes in favour of a placeholder board.
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2026-10-28 feat(pcb): point the XT60 footprint to the GrabCAD XT60PW-M model
    Belongs with ee9d478, which only removed the placeholder box because
    the add step failed on the deleted folder.

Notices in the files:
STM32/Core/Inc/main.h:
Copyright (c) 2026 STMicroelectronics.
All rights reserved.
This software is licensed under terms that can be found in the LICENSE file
